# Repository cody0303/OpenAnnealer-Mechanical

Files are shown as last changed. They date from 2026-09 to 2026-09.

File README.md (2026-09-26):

# OpenAnnealer — Mechanical

Mechanical design and assembly for [OpenAnnealer](https://github.com/cody0303/OpenAnnealer), an
automated induction annealer for cartridge cases. This repo covers the physical side only — case
feed, holder, coil mounting, and enclosure. Firmware/electronics live in the main
[OpenAnnealer](https://github.com/cody0303/OpenAnnealer) repo; this split mirrors the upstream
[OpenTrickler](https://github.com/eamars/OpenTrickler) project this fork is based on.

**Status: concept stage.** Design rationale, open assumptions, and next steps are in
[`docs/DESIGN.md`](docs/DESIGN.md) — read that before the CAD, since several parts here are
deliberately placeholders (no induction coil purchased yet, no motor locked in for the spare feed
motor) pending real hardware.

## Layout

- [`docs/`](docs) — design writeup, concept diagrams, photos as the build progresses
- [`cad/`](cad) — source CAD models (OpenSCAD — see [`cad/README.md`](cad/README.md))
- [`stl/`](stl) — print-ready STL exports
- [`assembly/`](assembly) — bill of materials, assembly notes

## Status

Nothing has been bench-tested yet. The design writeup is in [`docs/DESIGN.md`](docs/DESIGN.md).
The whole machine is modelled: the feeder, the funnel and swing arm (up to .338 Lapua Mag), the coil
mount, and the cabinet with its faces and the parts inside it. See [`cad/README.md`](cad/README.md),
which also covers the OpenSCAD nightly requirement, and
[`assembly/assembly.scad`](assembly/assembly.scad) for everything put together. Parts and
fasteners are in [`assembly/BOM.md`](assembly/BOM.md).

[`docs/concept_diagram.svg`](docs/concept_diagram.svg) predates the current feeder design and is
kept only as a sketch of the overall machine.

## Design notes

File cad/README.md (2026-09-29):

# CAD — OpenSCAD source

Parametric, text-based CAD for the printed parts.

## Requirements

**An OpenSCAD nightly build with `import-function` enabled** (Edit → Preferences → Features →
`import-function`). The [catchnhole](https://github.com/mmalecki/catchnhole) submodule uses
OpenSCAD's JSON `import()`, which the 2021.01 release doesn't have.

This matters because it fails *silently*: on a release build every `bolt()` call degrades to
undefined dimensions and renders as a pinhole with no countersink, while still exporting a
clean-looking, printable part. Check the console for `Ignoring unknown function 'import'`.

Clone with the submodule:

```bash
git submodule update --init --recursive
```

Headless render/export:

```bash
openscad --enable=import-function -o singulator.stl cad/feeder/singulator.scad
```

## Layout

- [`sharedDims.scad`](sharedDims.scad) — the dimensions parts share (hardware, stack spacings,
  the cabinet wall); the part files include it rather than hard-coding numbers.
  **Change shared values here, not in a part file.**
- [`feeder/layout.scad`](feeder/layout.scad) — where the feeder stack sits, derived from
  sharedDims; the left panel drills its holes from it.
- [`cabinet/boxLayout.scad`](cabinet/boxLayout.scad) — the cabinet box, what's inside it, and
  every face's cut-outs. Front is the screen end, back is where the USB ports come out, left is the
  panel the feeder mounts on, right is the wall across from it.
- [`feeder/`](feeder) — the feed subsystem, outside the cabinet.
- [`cabinet/`](cabinet) — printed parts inside the cabinet, plus `flatPanel.scad` (the flat-face
  helpers) and `boxLayout.scad`, which aren't parts.
- [`cabinetFlat/`](cabinetFlat) — the cabinet's six faces. The release also exports each one as a
  DXF for cutting (`tools/export_panel_dxf.py`), so nothing but faces belongs here. Faces taller
  than the bed (the ones with a `panelTile` setting) come out of the release as one STL per
  printing tile, `name-upper.stl` and `name-lower.stl`.
- [`../assembly/assembly.scad`](../assembly/assembly.scad) — the whole machine, view only, with
  clash checks. [`../assembly/BOM.md`](../assembly/BOM.md) lists parts and fasteners.

## Parts

| File | Part | Print material |
|---|---|---|
| [`feeder/hopper.scad`](feeder/hopper.scad) | Flat-backed pan; its boss doubles as the wheel's retaining wall, the base plate the case bases ride on, and the motor mount | PLA/PETG |
| [`feeder/singulator.scad`](feeder/singulator.scad) | Wheel with a rim pocket; one per case family, with the size embossed on the face | PETG/nylon |
| [`feeder/shaftAdapter.scad`](feeder/shaftAdapter.scad) | D-bore hub coupling the wheel to the motor shaft | PETG/nylon |
| [`feeder/funnel.scad`](feeder/funnel.scad) | Takes the case from the wheel down into the coil | PETG |
| [`feeder/hornMount.scad`](feeder/hornMount.scad) | Swing arm keyed to the servo's stock horn; carries the M5 thumbscrew the case stands on | PETG/nylon |
| [`cabinet/servoMount.scad`](cabinet/servoMount.scad) | Holds the MG90S inside the left panel | PETG |
| [`cabinet/heatsinkHolder.scad`](cabinet/heatsinkHolder.scad) | Holds the coil's two heatsinks; shares the funnel's upper bolt | PETG |
| [`cabinet/screenTilt.scad`](cabinet/screenTilt.scad) | Tilted screen and knob housing, front wall | PETG |
| [`cabinet/transformerCradle.scad`](cabinet/transformerCradle.scad) | Stand under the transformer (drawn for 15°) | PETG |
| [`cabinet/transformerShim.scad`](cabinet/transformerShim.scad) | Wedge on the cradle that steepens the transformer to 25° | PETG |
| [`cabinet/fanAdapter.scad`](cabinet/fanAdapter.scad) | 40 mm fan duct -- not placed since the driver board stood on end | PETG |
| [`cabinet/cornerBlock.scad`](cabinet/cornerBlock.scad) | Corner block the faces screw into (12 off) | PETG |
| [`cabinetFlat/`](cabinetFlat) | Left panel (`sidePanel`), front, back and right walls, lid and base: 6 mm, printed as tiles or cut from ply | PETG / ply |

## Hardware notes

- **Drive pins** are M3 socket-head bolts threading up through the adapter (head recessed in its
  underside) and protruding to engage the wheel. The bolt cavity is scaled 0.95 so the shank is
  2.85mm — a thread-forming fit in plastic. **M3×20** gives ~11mm of engagement into the wheel;
  M3×16 only gives ~7mm.
- **Set screw** is an M3 through a heat-set insert, aligned with the D-flat.
- **Motor bolts** counterbore into the top of the base plate. The wheel rides on that face, so the
  pocket depth (`3 × countersink`) has to exceed the 3mm head height — currently `countersink=1.33`
  for a 3.99mm pocket.

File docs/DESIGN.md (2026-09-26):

# OpenAnnealer — Mechanical Design

Status: **concept / first pass, not yet bench-verified.** This document responds to the mechanical
design brief handed off from the firmware side of the project (see
[OpenAnnealer](https://github.com/cody0303/OpenAnnealer)). It proposes one coherent, buildable
concept for every open mechanical question in that brief, flags every assumption that still needs
a real part or a real case in hand to confirm, and leaves the things that are genuinely still open
as open. Diagram: [`concept_diagram.svg`](concept_diagram.svg).

## Assumptions and open items (read this first)

These are the load-bearing assumptions behind everything below. If any of them are wrong, the
affected subsystem needs rework before it's worth modeling in CAD:

| # | Assumption | Why it matters | Confirmed? |
|---|---|---|---|
| 1 | Case range to support: pistol through magnum, roughly 0.75"–2.85" (19–72 mm) case length | Drives hopper/disk and holder-insert sizing | No — working range, not measured against real cases yet |
| 2 | Induction coil not yet purchased | Coil bore ID and winding height set the minimum clearance the holder column and cook-zone height must fit inside | No — mount is designed adjustable/oversized until a real coil is on hand |
| 3 | Feeder motor and the second ("spare") motor's frame size (NEMA form factor) | Determines mounting bolt patterns | **Not locked** — see [Second (spare) motor mounting](#second-spare-motor-mounting) below; do not cut a fixed bolt pattern for either motor into a structural part |
| 4 | Fabrication: FDM 3D printing for all custom parts | Drives wall thickness, tolerance, and material choices below | Confirmed by you |
| 5 | New enclosure/base, no chassis carryover from OpenTrickler | Frees up the layout | Confirmed by you |

Everything downstream of #1–#3 is written to be **adjustable or swappable**, specifically so that
getting one of these assumptions wrong later costs a reprinted insert, not a redesign.

## Kinematic concept

One column, top to bottom (see diagram):

1. **Hopper** — a flat-backed pan leaning ~45°, loosely filled with cases in bulk (no
   hand-orienting). They stand base-down on its base plate and slide toward the bottom outlet.
2. **Singulator wheel** — driven by the feeder stepper, its rim sitting in the pan's outlet so its
   cylindrical side is the floor under the pile. A pocket in the rim takes one case off the bottom
   of the pile and carries it round, held in by the hopper's retaining wall, to an angled discharge
   bore that drops it into the holder below.
3. **Coil zone** — the case's neck/shoulder ("cook zone") sits inside the induction coil, supported
   from below by a shelf mounted on the swing arm.
4. **Swing arm** — rotates about a vertical pivot, in the horizontal plane, between two servo-
   commanded positions:
   - **HOLD** — shelf positioned directly under the coil bore, case supported.
   - **DROP** — shelf swung just far enough to clear the coil body; case is no longer supported and
     falls straight down.
5. **Drop point** — no funnel or catch tray in this design; the case falls straight down into
   whatever catch area you provide below (sized separately, per your call).

This matches the firmware's model exactly: the servo only ever commands two fixed ratios
(`HOLDER_RATIO_HOLD` / `HOLDER_RATIO_DROP`, see
[`servo_gate.h`](https://github.com/cody0303/OpenAnnealer/blob/main/src/servo_gate.h)) and never
receives a per-case-length or per-caliber value. All length/diameter compensation has to live in
the mechanism, set by hand before a run — which is exactly what the brief specifies ("a simple
swing arm with an adjustment nut... a manual, physical setting, not something the firmware
commands per case").

## Subsystem designs

### Case holder (swing arm)

- A single arm rotates on a vertical pivot shaft, driven by the case-holder servo, between two
  commanded positions (HOLD/DROP). **No mechanical hard-stop hardware is included** — the RC servo
  is inherently position-controlled (it always drives to whichever duty cycle it's told), so the
  servo itself is the repeatable element, exactly as `servo_gate.c` implements it
  (`close_duty_cycle`/`open_duty_cycle`, two fixed values). A physical stop can be retrofitted later
  if bench testing turns up slop under load, but nothing is designed in preemptively.
- The sweep only needs to be large enough for the shelf/case to clear the coil body, not a fixed
  90°+ arc. For an arm of radius `r` (pivot to case centerline) and a coil of outer radius `R`
  (measured from the HOLD centerline, i.e. from the case's position), the chord the case travels at
  swing angle `θ` is `2r·sin(θ/2)`; solving for the angle that just clears the coil plus a small
  margin `m`: `θ_min = 2·asin((R + m) / (2r))`. E.g. at `r` = 50 mm and `R` = 25 mm coil radius with
  a 5 mm margin, `θ_min ≈ 35°` — nowhere near 90°. Longer arms need even less angle for the same
  coil. **Finalize this once a real coil OD and arm radius are chosen**; the diagram shows a small
  sweep as the working assumption instead of the earlier 90–100° figure.
- At the working end of the arm, a **vertical stud** carries a shelf/cup that slides up or down the
  stud and locks with a **thumb nut** — this is the "adjustment nut" from the brief. Raising or
  lowering the shelf changes how far a case sits down into the guide column, which is what lines
  up the case's neck/shoulder with the coil regardless of overall case length. This setting is
  physical and manual, touched once per case type, never per-cycle.
- The shelf top is a **swappable insert cup**, not a single universal pocket. Rim and extractor-
  groove diameters cluster into a handful of families rather than varying smoothly (this is why
  press shellholders come in a fixed set of groups, not one universal size) — a single hole sized
  for a .338 Lapua rim would let a 9mm case rock or tip, and a hole sized for 9mm won't accept a
  magnum rim at all. Four printed insert cups covering the ranges in the table below is a small,
  cheap part count for a large gain in reliability at both ends of the range. Insert retention:
  press-fit shoulder into a shallow recess on the shelf, sized for a firm hand-press fit in PETG
  (no fasteners needed — it's a tool-less swap between range sessions).

### Hopper + singulator wheel

Modelled on ARC Precision / ADG's annealer. **CAD**: [`cad/feeder/`](../cad/feeder) — hand-written,
with every dimension in [`sharedDims.scad`](../cad/sharedDims.scad).

- **Hopper**: a flat-backed pan leaning back ~45°, open at the top for loading. Cases are dumped in
  loose and stand base-down on the pan's base plate, fully contained (52mm of wall depth against a
  44.7mm case). The lean slides the pile down, and the pan's lower sides — converging at
  `feedAngle` — funnel it into the bottom outlet.
- **The wheel's rim sits in that outlet, and its cylindrical *side* is the floor the bottom of the
  pile rests on.** This is the detail that makes the mechanism work and the easiest thing to get
  wrong: cases do not stand on the wheel's *face*, and the pocket is not a hole through the face.
- **Singulator wheel**: a pocket cut into the rim takes one case off the bottom of the pile per
  revolution; the rest of the pile keeps resting on the smooth tread, so surplus cases reject
  themselves. The pocket is recessed so a seated case sits flush with the rim, which lets the
  retaining wall hug the wheel at 2.5mm. Case size is embossed on the face so wheels are
  identifiable.
- **The funnel is derived, not eyeballed**: `singulatorExposureAngle` sets how much of the rim the
  pile can touch; the chord it subtends *is* the outlet width, and the converging sides fall back
  from it at `feedAngle`. Resizing the wheel moves the hopper to match automatically.
- **One part does four jobs.** The hopper's boss is the wheel's retaining wall (z=8–40, covering 72%
  of the case length — enough that the case's centre of mass sits well inside it), its lower 8mm is
  the base plate the case bases ride on, and the motor bolts straight to the underside — so one
  printed part carries the lot, with no stack-up between separate plates.
- **Discharge** is an angled bore at the bottom of the wheel: the case slides axially out of its
  pocket through the base plate, and the bore's 30° tilt steers it clear of the motor. It opens a
  ~40° release window in the retaining wall.

Verified numbers at the current dimensions (80mm wheel, 100×100 pan):

| Check | Value |
|---|---|
| Chute alignment to the case at bottom-of-rotation | 0.33mm |
| Chute to NEMA17 body | 3.85mm (tightest clearance in the assembly) |
| Outlet chord vs. case diameter | 5.89× (hopper practice wants 4–6× to avoid bridging) |
| Hopper capacity | ~56 cases realistic, 47 pessimistic |

Capacity is the one sitting on its requirement rather than clear of it — the 50-case target is met
on a realistic packing estimate and missed on a pessimistic one. It's derived from packing
geometry, so it's worth checking against a real handful of brass.

This subsystem still needs bench iteration: pickup reliability (hopper lean, pocket depth, tread
width) is not something drawings settle.

### Coil mount

- Since no coil is bought yet, the mount is deliberately **not** built around specific coil
  dimensions. It's a bracket with a **vertical slot** on at least one side, so coil height is
  field-adjustable with a single screw once a real coil arrives — this sets which part of the case
  ends up in the strongest field region without redesigning anything.
- Minimum bore clearance to design toward: the holder column's largest liner OD plus wall
  thickness plus a few mm working clearance — call it **≥25 mm clear ID** through the coil as a
  starting target. **This number must be checked against the actual coil once purchased** before
  finalizing the guide-column OD; it's the one dimension in this document most likely to force a
  revision.

### Drop point

- No funnel or catch tray in this design — the case falls straight down from the DROP position.
  Catch-area sizing/placement is on you; this repo only needs to keep the drop point's location
  (position under the coil, height above your bench/tray) documented once the frame is built, so a
  catch area can be sized against it.

### Second (spare) motor mounting

The firmware brief describes this as hardware-present-but-unused, reserved for a future
feed-path function, "no mechanical role assigned yet." Since you're not locked to a specific motor
for either the feeder or this spare position, **no structural part in this design commits to a
fixed motor bolt pattern.** Concretely:

The feeder motor itself *is* mounted — it bolts straight to the underside of the hopper's base
plate ([`cad/feeder/hopper.scad`](../cad/feeder/hopper.scad)), which is the only part carrying a
motor bolt pattern. Two details there are easy to get wrong: the heads counterbore into the *top*
of that plate, which is the face the wheel runs on, so the pocket has to be deeper than the 3mm
head height (`countersink=1.33` gives 3.99mm); and the bolt circle has to stay clear of the
discharge bore.

For the **second, still-unassigned** motor:

- Reserve a flat, unobstructed mounting **envelope** near the hopper/singulator (roughly
  50×50 mm clear area plus shaft clearance) rather than drilling a bolt circle now.
- When a motor is actually chosen for this position (and, if it turns out to differ from what's
  currently on the feeder, for that one too), the mounting bolt pattern goes on a small
  **printed adapter plate** — a single reprintable part between the motor and the frame — instead
  of being cut into the main structure. NEMA 14 and NEMA 17 motors use different bolt spacing
  (26 mm vs. 31 mm square, respectively); an adapter plate absorbs that difference for the cost of
  one reprint instead of a structural rework.
- No specific future function (hopper advance, multi-case carousel, etc.) is assumed here — the
  brief is explicit that none has been designed yet, and committing this document to one would be
  guessing.

### Frame / base

- New enclosure, no chassis carryover. Hopper + singulator disk → coil → holder → open drop point,
  mounted to a flat base plate; electronics enclosure (LCD/encoder module, control board) mounts
  wherever is convenient on or beside the base — no mechanical constraint from that side beyond
  enclosure volume, per the brief.

## Case-family reference groups (working assumption)

Used to size the swappable disks and holder inserts above. These are standard published SAAMI
case dimensions, not measurements — **verify against your actual cases before cutting the first
insert**, especially at the top end (this document assumes "magnum" tops out around .338 Lapua
Magnum-class, not the largest belted or beltless magnums that exist):

| Family | Example calibers | Case length range | Rim/groove Ø range |
|---|---|---|---|
| Small (pistol/small rifle) | 9mm Luger, .380 ACP, .223/5.56 | ~17–45 mm | ~9.5–9.7 mm |
| Medium | .45 ACP, .30-30, .243 Win | ~23–52 mm | ~11.2–12.0 mm |
| Large | .308 Win, .30-06, .270 Win | ~51–64 mm | ~12.0 mm |
| Magnum | .300 Win Mag, .338 Lapua Mag | ~64–72 mm | ~12.0–14.9 mm (belted magnums: belt Ø ~13.0 mm) |

If real use turns out to need calibers past .338 Lapua Magnum (e.g. .50 BMG-class), that's a fifth
family and a larger coil, not a change to this structure.

## Servo torque sanity check

Brief specifies a TowerPro SG90/MG90S-class servo (per the firmware README). Worst case load is
the heaviest case + insert cup, at the arm's working radius:

- Heaviest case (empty .338 Lapua Mag brass): ~26 g
- Insert cup + shelf hardware: ~15 g estimated
- Arm radius to load: ~50 mm (0.05 m)

Static torque required: `(0.026 + 0.015) kg × 9.81 m/s² × 0.05 m ≈ 0.020 N·m ≈ 0.21 kgf·cm`

MG90S rated stall torque is ~2.2 kgf·cm (4.8 V) / SG90 ~1.6 kgf·cm — roughly **8–10× margin** even
at the heaviest end of the range, before accounting for the servo's own gear-hold. No torque
concern with the specified servo; this isn't a constraint on arm length or insert weight within
any sane design.

## Materials and fabrication (FDM)

- **Near the coil** (holder shelf, insert cups, coil mount bracket, drop chute): use **PETG or nylon**, not PLA/ABS. These parts sit closest to a part that gets hot
  and radiates during dwell; PLA softens around 60°C and ABS around 100°C, both low enough to be a
  real concern this close to an induction-heated case. PETG (~80°C HDT) is the practical minimum;
  nylon is better if you see any softening in testing.
- **Away from the coil** (base plate, hopper, motor mounts): PLA or PETG is fine — no thermal
  exposure to plan around.
- Standard FDM tolerances (±0.2 mm) are fine everywhere except the insert-cup-to-shelf press fit —
  plan a test coupon for that before printing full-size parts, since press-fit tolerance is
  printer- and material-dependent.

## Bill of materials (mechanical, first pass)

See [`assembly/BOM.md`](../assembly/BOM.md).

## Next steps requiring physical hardware (not deferrable to more writing)

1. **In progress**: [`cad/feeder/`](../cad/feeder) has a first-pass hopper + singulator disk + face
   plate + drive hub, sized for a .223 Rem/5.56 NATO prototype off SAAMI reference dimensions —
   verify those against real fired brass with calipers before printing full-size parts (`cad/`
   README has the two fits worth test-coupon-ing first: the drive pin fit and the magnet press-fit).
2. Print that first prototype and bench test hopper pickup reliability and singulation before
   committing to CAD for the other three case families (Small/Medium/Magnum) or for the holder
   assembly below it. Pickup reliability (hopper angle, disk tilt, pocket depth) is the part most
   likely to need several iterations — plan for that rather than expecting the first print to work.
3. Purchase the induction coil; re-check the ≥25 mm clear-bore target and recompute the arm's
   minimum swing angle (formula above) against its actual OD.
4. Decide the second motor before modelling a mount for it — and confirm the feeder motor's actual
   shaft diameter and flat depth against `shaftDia`/`shaftDwidth` in
   [`cad/sharedDims.scad`](../cad/sharedDims.scad).
5. Model the holder swing arm, shelf, insert cup, coil mount bracket, and drop chute — not started
   yet; the feeder subsystem above was the starting point.

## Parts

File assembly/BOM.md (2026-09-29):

# Bill of Materials

Status: work in progress. Everything below is modelled and checked in `assembly/assembly.scad`;
nothing has been bench-tested. Screw lengths assume 6 mm cabinet faces (`cabinetWallThk` in
`cad/sharedDims.scad`) — re-check them if that changes.

## Printed parts (FDM)

| Part | Material | Qty | Notes |
|---|---|---|---|
| Hopper (pan) | PLA/PETG | 1 | Boss doubles as wheel retaining wall, base plate and motor mount — `cad/feeder/hopper.scad` |
| Singulator wheel | PETG/Nylon | 1 per case family | Rim pocket, size embossed on the face — `cad/feeder/singulator.scad` |
| Shaft adapter | PETG/Nylon | 1 | D-bore hub, couples wheel to motor shaft — `cad/feeder/shaftAdapter.scad` |
| Funnel | PETG | 1 | Wheel discharge down into the coil — `cad/feeder/funnel.scad` |
| Horn mount | PETG/Nylon | 1 | Keys to the servo's stock horn; carries the thumbscrew — `cad/feeder/hornMount.scad` |
| Servo mount | PETG | 1 | MG90S hangs in it on its ears — `cad/cabinet/servoMount.scad` |
| Heatsink holder | PETG | 1 | Holds the two coil heatsinks — `cad/cabinet/heatsinkHolder.scad` |
| Screen housing | PETG | 1 | Tilted screen and knob, front wall — `cad/cabinet/screenTilt.scad` |
| Transformer cradle | PETG | 1 | Stand under the transformer, drawn for 15° — `cad/cabinet/transformerCradle.scad` |
| Transformer shim | PETG | 1 | Wedge on the cradle's slab, steepens the transformer to 25° — `cad/cabinet/transformerShim.scad` |
| Fan duct | PETG | 1 | 40 mm fan — not placed yet since the driver board stood up — `cad/cabinet/fanAdapter.scad` |
| Corner block | PETG | 12 | Four vertical corners × base, seam and lid — `cad/cabinet/cornerBlock.scad` |

## Cabinet faces

6 mm, either printed or cut from plywood from the DXF (`tools/export_panel_dxf.py`, or the release
artifacts). The front, back, left and right walls are taller than the 200 mm bed; printed, each is
two tiles joined by a half-lap, glued and bolted. The release has each tile as its own STL
(`frontWall-upper.stl`, `frontWall-lower.stl`, …).

| Face | File | Notes |
|---|---|---|
| Left panel | `cad/cabinetFlat/sidePanel.scad` | The feeder stack, heatsink holder, servo mount and Pico board bolt to it |
| Front wall | `cad/cabinetFlat/frontWall.scad` | Screen housing |
| Back wall | `cad/cabinetFlat/backWall.scad` | Pico board's USB-C ports, IEC inlet |
| Right wall | `cad/cabinetFlat/rightWall.scad` | Corner-block screws only, for now |
| Lid | `cad/cabinetFlat/lid.scad` | Nothing mounted to it, for servicing |
| Base | `cad/cabinetFlat/base.scad` | Transformer cradle screws up into it |

Each wall file has `feederSide`; a right-hand build exports its faces with `"right"`.

## Fasteners

| Item | Spec | Qty | Where |
|---|---|---|---|
| M5 bolt | M5×20 button head | 6 | Through the left panel into captive nuts: hopper 2, servo mount 2, funnel lower 1, heatsink holder bottom 1 |
| M5 bolt | M5×25 button head | 1 | Through the left panel, the heatsink holder and into the funnel's upper nut |
| M5 nut | hex | 7 | Captive in the hopper, servo mount, funnel and heatsink holder |
| Thumbscrew | M5, ~50 long, + 2 jam nuts | 1 | Case stop in the horn mount; shorter cases ride up it |
| M3 screw | M3×10 button head | 32 | Through the faces into the corner blocks |
| M3 heat-set insert | `m3InsertD` × `m3InsertDepth` | 36 | Corner blocks, 3 each (the seam blocks' third one is unused) |
| M3 bolt + nut + washer | M3×10 button head | 7 | Tile half-lap bolts, nut inside (left 1, front 2, back 2, right 2) |
| M3 screw | M3×10 | 4 | Front wall into the screen housing's ear inserts |
| M3 heat-set insert | | 4 | Screen housing ears |
| M3 self-tapper | ~M3×6 | 4 | Screen board onto the housing's standoffs |
| M3 screw + washer | M3×10 | 4 | Up through the base's slots into the cradle's feet; the washers bridge the slots |
| M3 heat-set insert | | 4 | Transformer cradle feet |
| Zip tie | ≤5 mm wide | 2 | Over the transformer, through the shim and cradle |
| M3 screw | M3×10 | 4 | Wall into the fan duct's inlet inserts (fan not placed yet) |
| M3 screw | M3×25 | 4 | Through the fan into the duct's seat inserts |
| M3 heat-set insert | | 8 | Fan duct: 4 in the inlet face, 4 in the seat |
| M3 standoff | M3×10 female–female | 4 | Pico motor board off the left panel |
| M3 screw | M3×10 / M3×6 | 4 / 4 | Standoffs: through the panel / through the board |
| M4 heat-set insert | `m4InsertD` × `m4InsertDepth` | 2 | Heatsink holder, one each side |
| M4 screw | length to suit the heatsinks | 2 | Heatsinks onto the holder |
| Motor screw | M3 socket head | 4 | Counterbored into the top of the hopper's base plate |
| Drive pin | M3×20 socket head | 2 | Thread into the shaft adapter, protrude ~11 mm into the wheel. M3×16 only reaches ~7 mm |
| Hub set screw | M3 grub + heat-set insert | 1 | Bears on the shaft's D-flat |
| Horn screws | the servo's own small self-tappers | 2+ | Horn into the horn mount |

## Other hardware

| Item | Qty | Notes |
|---|---|---|
| Grommet, for an 11 mm hole | 2 | Coil leads through the left panel |
| Edge trim (optional) | ~60 mm | The 18 × 8 stepper cable slot in the left panel |
| 40 × 20 mm fan | 1 | 32 mm hole pitch |
| NEMA 17 stepper | 1 | Feeder wheel |
| MG90S servo | 1 | Swing arm |
| Pico motor expansion board + Pico 2 W | 1 | eamars/RaspberryPi-Pico-Motor-Expansion-Board |
| IEC inlet with switch | 1 | 47 × 27.5 mm panel cut-out, low on the back wall above the relay; up to ~35 mm deep behind the wall |
| Double-sided mounting tape | — | Driver board and relay |

The coil, its heatsinks, the transformer and the driver board are harvested from an induction
heater; confirm their sizes against `cad/cabinet/boxLayout.scad`.

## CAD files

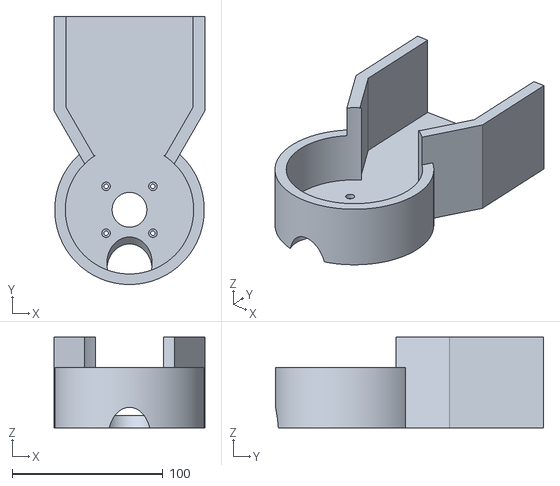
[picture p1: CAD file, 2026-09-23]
stl/hopper.stl
100.0 x 177.5 x 60.0

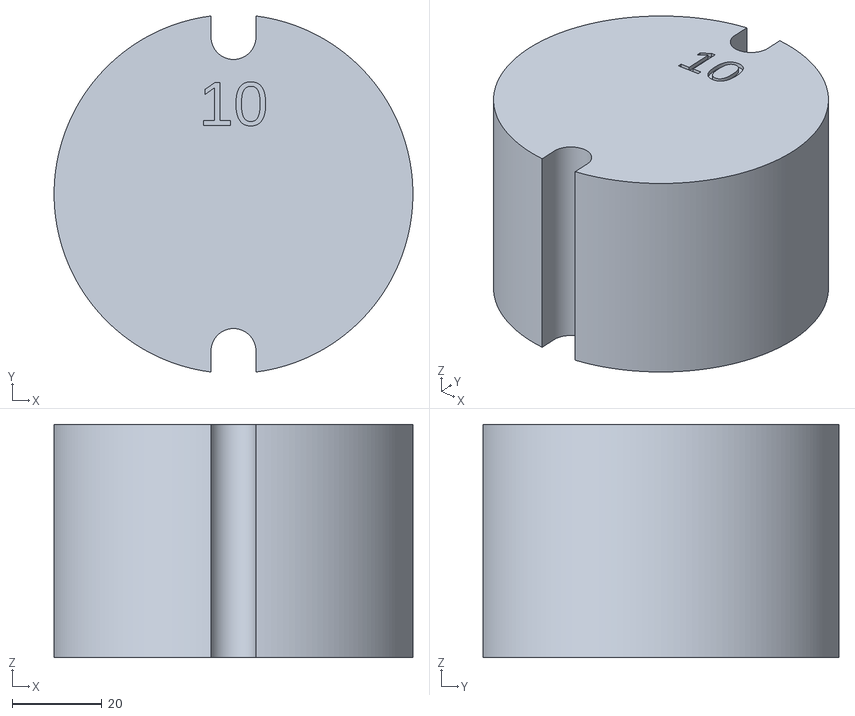
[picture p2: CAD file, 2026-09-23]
stl/singulator1.stl
80.0 x 79.4 x 52.0

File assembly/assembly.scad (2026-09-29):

// OpenAnnealer -- full machine assembly preview.
//
// Open this file and hit F5. It pulls the real part files in from cad/feeder/,
// so it always reflects whatever the parts currently are: edit hopper.scad or
// singulator.scad and this updates with them. Nothing here is a copy of a part.
//
// Lives in assembly/ rather than cad/ on purpose -- the release workflow runs
// `find cad -name "*.scad"` and renders every hit to STL, and this is a
// view-only file, not a part. Don't export it.
//
// Only things with no source file are modelled locally: the motor, servo,
// induction coil, thumbscrew, grommets, the cases, the harvested heater's
// parts and the other electronics. Those are rough stand-ins for
// visualisation, not parts to print.
//
// Where everything sits comes from cad/feeder/layout.scad (the feeder stack)
// and cad/cabinet/boxLayout.scad (the box and what's in it), which the parts
// share, so their holes always land on the parts. The world frame is in
// layout.scad: Z is the drop axis, the funnel arm points +Y to the cabinet's
// left panel. The box's front, back, left and right are named in boxLayout.
// Stack spacings are in sharedDims.
//
// feederSide flips the unit left/right. It does it by turning the feeder
// +/-90 deg about the drop axis, not by mirroring: the hopper is symmetric
// with mounting on both sides, so the same printed parts build either hand.

include <../cad/feeder/layout.scad>

/* [Feeder] */
/* The feeder leans back by mountAngle and the drop bore is cut at mountAngle
   (both from sharedDims), so the discharge always falls dead vertical.
*/
// which side of the stack the feeder sits, seen from outside the cabinet
feederSide = "left";  // [left, right]

/* [Induction coil mock] */
coilTurns = 4;
coilID    = 26;
coilPitch = 5;          // tube OD and the leads' spacing are in sharedDims

/* [Thumbscrew mock] */
thumbHeadD = 14;
thumbHeadH = 7;
nutAcross  = 9.2;
nutH       = 4;

/* [Mock case -- .338 Lapua Mag, the longest it takes] */
// Approximate. The thumbscrew is raised to put the shoulder/neck junction in
// the middle of the coil. .223 Rem: 44.7, 9.5, 6.4, 32, 38
caseLen      = 69.2;
caseBodyD    = 14.9;
caseNeckD    = 9.5;
caseShoulder = 54.9;    // base to the body/shoulder junction
caseNeck     = 60.9;    // base to the shoulder/neck junction

/* [Coil leads mock] */
leadIntoCabinet = 15;   // how far the leads run on past the wall's inner face, into the heatsinks

/* [Cabinet box] */
/* Flat faces (ply or print, cabinetWallThk thick) -- the left panel
   (cad/cabinetFlat/sidePanel.scad), front, back and right walls, lid and base
   (the other files there) -- screwed into printed corner blocks
   (cad/cabinet/cornerBlock.scad) in the four vertical corners at the base,
   the tile seam and the top. Printed faces split at the seam and meet in a
   half-lap, bolted through with nuts inside. Where everything in and on the
   box sits, and the screen tilt, the harvested heater's pose and the Pico
   board's settings, are in cad/cabinet/boxLayout.scad, which the faces share.
*/
boxCutaway    = false;  // drop the lid, front and right walls to see inside

/* [Display] */
showCases   = true;
showMotor   = true;
showCoil    = true;
showFunnel  = true;
showArm     = true;
showCabinet = true;     // the left panel and the lead grommets
showBox     = true;     // the rest of the cabinet
showElectronics = true;
checkTransformer = false;   // true: draw only where the transformer hits something -- nothing drawn means clear
checkCorners     = false;   // true: draw only where the corner blocks hit the servo, its mount or the swinging arm
armSwing         = 45;      // the arm's swing each way from the drop axis, for checkCorners -- the wall slot limits it
hopperAlpha = 0.35;   // 1 = solid; lower to see the wheel and motor through it
funnelAlpha = 1;
cabinetAlpha = 0.35;     // lower to see the leads and servo inside

// +1 puts the feeder on -X (left, seen from outside), -1 on +X
hand       = (feederSide == "right") ? -1 : 1;
feederSpin = 90 * hand;     // turns the hopper's +/-X side square to the wall

coilR = coilID/2 + coilTube/2;              // coil tube centreline radius
// the mock case's base: shoulder/neck junction mid-coil, no lower than the
// thumbscrew goes
caseSeatZ = max(caseBaseZ, coilZ - caseNeck);

// ---------------------------------------------------------------------------
// The real parts, pulled straight from their own files
// ---------------------------------------------------------------------------
// These are wrapped as modules in their own files and pulled in with `use`.
// hopper, shaftAdapter, funnel and servoMount have to be: they `use
// <catchnhole>` themselves, and a nested `use` resolves relative to whichever
// file pulls it in, so `include`-ing them from here can't find it.
use <../cad/feeder/hopper.scad>;        // provides hopper()
use <../cad/feeder/shaftAdapter.scad>;  // provides shaftAdapter()
use <../cad/feeder/funnel.scad>;        // provides funnel()
use <../cad/cabinet/servoMount.scad>;   // provides servoMount()
use <../cad/cabinet/heatsinkHolder.scad>; // provides heatsinkHolder(), heatsinkHolderSize(), heatsinkHolderBackset()
use <../cad/cabinet/transformerCradle.scad>; // provides transformerCradle(), transformerCradleFit()
use <../cad/cabinet/fanAdapter.scad>;    // provides fanAdapter(), on_seat(), fanAdapterMaxX(), fanAdapterMinX(), fanAdapterScrews(), fanAdapterInlet(), fanAdapterSeatT()
use <../cad/cabinetFlat/sidePanel.scad>; // provides sidePanel(), sidePanelTile(), panelFeatures(), panelSplitZ(), lead_hole_2d()

// The other two have no nested `use`, so they can be pulled straight in.
// If you ever add a `use <...>` to one of them it'll break here, and will need
// the same module wrapper as the ones above.
module part_singulator() { include <../cad/feeder/singulator.scad>; }
module part_hornMount()  { include <../cad/feeder/hornMount.scad>; }
use <../cad/cabinet/screenTilt.scad>;    // provides screenTilt(), screenTiltWallFeatures(), in_plate_frame()

use <../cad/cabinet/cornerBlock.scad>;   // provides cornerBlock()
use <../cad/cabinet/flatPanel.scad>;     // provides flat_part(), flat_tile()

// Where the box and everything in and on it sits -- shared with the faces'
// part files. Needs `hand`, above, and the files it lists `use`d, which they are.
include <../cad/cabinet/boxLayout.scad>

// Takes children drawn in hopper.scad's own frame and puts them in the world:
// lean back, slide the bore exit onto the origin, then spin about the drop axis.
module in_feeder_frame() {
    rotate([0, 0, feederSpin])
     translate([0, -exitTiltY, -exitTiltZ])
      rotate([mountAngle, 0, 0])
        children();
}

// ---------------------------------------------------------------------------
// Stand-ins for things with no source file
// ---------------------------------------------------------------------------
module mock_case() {
    cylinder(d = caseBodyD, h = caseShoulder);
    translate([0,0,caseShoulder])
        cylinder(d1 = caseBodyD, d2 = caseNeckD, h = caseNeck - caseShoulder);
    translate([0,0,caseNeck]) cylinder(d = caseNeckD, h = caseLen - caseNeck);
}

// NEMA17. Z=0 is the motor face; body hangs below, shaft above.
module mock_motor(shaftLen = 24) {
    translate([-21.15,-21.15,-40]) cube([42.3, 42.3, 40]);
    cylinder(d = 22, h = 2);
    cylinder(d = shaftDia, h = shaftLen);
}

module mock_coil() {
    for (i = [0 : coilTurns - 1])
        translate([0, 0, i*coilPitch - (coilTurns-1)*coilPitch/2])
            rotate_extrude() translate([coilID/2 + coilTube/2, 0]) circle(d = coilTube);
}

// A copper tube run through a list of points.
module tube_path(pts, d) {
    for (i = [0 : len(pts) - 2])
        hull() {
            translate(pts[i])     sphere(d = d, $fn = 24);
            translate(pts[i + 1]) sphere(d = d, $fn = 24);
        }
}

// The two coil leads: each leaves its end turn tangentially, heading for the
// wall, closes up to leadGap, then runs straight through the grommet.
module mock_leads() {
    for (s = [1, -1]) {
        turnZ = coilZ + s * (coilTurns - 1) * coilPitch / 2;
        tube_path([
            [s * coilR,     0,              turnZ],
            [s * coilR,     coilR + 5,      turnZ],
            [s * leadGap/2, coilR + 20,     leadZ],
            [s * leadGap/2, clDist + cabinetWallThk + heatsinkHolderBackset() + leadIntoCabinet, leadZ]
        ], coilTube);
    }
}

// The heatsink holder in place: its +X end face on the inside of the wall,
// centred between the leads.
module place_holder() {
    translate([0, clDist + cabinetWallThk + heatsinkHolderSize()[0] - heatsinkLen/2, leadZ]) rotate([0, 0, -90]) children();
}
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

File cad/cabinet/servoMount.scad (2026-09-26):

include <../feeder/layout.scad>
use <../../catchnhole/catchnhole.scad>;

// Holds the MG90S end-on, short end toward the cabinet wall, so the arm's
// swing is symmetric about it and the same mount works with the feeder on
// either side. The servo drops into the pocket from above and hangs on its
// ears; M5 bolts come in through the cabinet wall into captive nuts, the same
// way the hopper and funnel mount.
//
// Origin: output shaft axis. z = 0 is the top face, where the ears sit. The
// face that bolts to the wall is at y = -(servoBackset - cabinetWallThk), so
// +Y points away from the wall, into the cabinet.

//servoClear, servoMountH and servoMountBoltX come from layout.scad, which
//the side panel shares, so its bolt holes always line up with this part
earPilotD   = 1.6;                                      //self-tappers through the servo's ears
mountH      = servoMountH;                              //ear underside down to the case bottom
mountWallY  = -(servoBackset - cabinetWallThk);         //the face against the wall
bodyCenterY = servoBodyL/2 - servoShaftToEnd;           //case centre, from the shaft
mountFarY   = bodyCenterY + servoEarSpan/2 + 3;         //just past the far ear's tip
mountBoltX  = servoMountBoltX;
mountHalfW  = mountBoltX + wallThickness + 4;
//the servo's cable leaves the case at its wall-side end, low down: a notch through
//the mount's end there, open at the bottom, lets it bend straight down against the wall.
//It's set by what's left above it: tilted in for insertion, the servo's cable dips
//to 8 mm below the ears' underside, so no more than that (the wall-side ear's pilot
//breaks into the notch -- fine)
cableNotchW    = 6;
cableNotchRoof = 7;                                     //mount left above the notch -- 8 at most
cableNotchH    = mountH - cableNotchRoof;               //up from the case bottom

assert(bodyCenterY - servoEarSpan/2 > mountWallY,
       "the servo's wall-side ear hits the cabinet wall -- increase servoBackset");
assert(cableNotchRoof <= 8, "the cable notch is too shallow for the servo's cable as it's tilted in");

// Wrapped as a module so assembly/assembly.scad can place it.
module servoMount() {
    difference(){
        //main block
        translate([-mountHalfW, mountWallY, -mountH])
            cube([2*mountHalfW, mountFarY-mountWallY, mountH]);

        //pocket the case drops through
        translate([-(servoBodyW/2+servoClear), -(servoShaftToEnd+servoClear), -mountH-1])
            cube([servoBodyW+2*servoClear, servoBodyL+2*servoClear, mountH+2]);

        //notch for the servo's cable, at the wall-side end
        translate([-cableNotchW/2, mountWallY - 1, -mountH - 1])
            cube([cableNotchW, -(servoShaftToEnd + servoClear) - mountWallY + 2, cableNotchH + 1]);

        //pilots for the ear screws
        for (y = [bodyCenterY-servoEarHolePitch/2, bodyCenterY+servoEarHolePitch/2])
            translate([0, y, -8])
                cylinder(h=9, d=earPilotD);

        //mounting nut interface, mirrored so the mount is symmetric
        for (side = [0, 1]) mirror([side, 0, 0]) {
            translate([mountBoltX, mountWallY+wallThickness, -mountH/2])
                rotate([-90,0,0])
                    nutcatch_sidecut("M5", "hexagon", height_clearance=0.2, width_clearance=0.2);
            translate([mountBoltX, mountWallY, -mountH/2])
                rotate([-90,0,0])
                    bolt("M5", length=(wallThickness+nut_height("M5")+5), kind="headless", length_clearance=1);
        }
    }
}

servoMount();

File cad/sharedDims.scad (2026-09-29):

$fn=180;

/* [Printer] */
printBed            = 200;

/* [Hardware] */
m3InsertD           = 4.0;  //M3 heat-set insert hole -- check your insert's datasheet
m3InsertDepth       = 6.2;  //for a 5.7 mm long insert, plus a little for melt-back
m4InsertD           = 5.0;
m4InsertDepth       = 8.0;

/* [Shaft Adapter] */
adapterDia      = 20;
pinLatOffset    = 6;
numPins         = 2;

//overall
clDist              = 60;

/* [Hopper] */
wallThickness   = 5;
baseThickness   = 8;
hopperWidth     = 100;
hopperHeight    = 50;
hopperDepth     = 60;
hopperConvergeAngle       = 30;
dropHoleSize    = 30;
mountAngle      = 45;
//NEMA17 motor dimensions
shaftSquareDim      = 3;
shaftDia            = 5;
shaftDwidth         = 4.5;
flatLength          = 12;
motorHolePatternX   = 31;
motorHolePatternY   = 31;
motorClearanceCircle= 23;

/* [Singulator] */
singulatorDiameter      = 80;
singulatorExposureAngle = 90;
numHoles                = 4;
caseCutout              = 10;

/* [Funnel] */
topDia              = 40;
exitDia             = 20;
funnelHeight        = 30;

/* [Movable Support] */
supportScrewSize    = 6.6;
supportThickness    = 6;
cabinetWallThk      = 6;  //cabinet faces (ply or print); the servo mount bolts to the inside of the left panel
cornerBlock         = 20; //printed blocks in the cabinet's vertical corners -- at the base, the tile seam and
                          //the top; every wall screws into them
tileLap             = 16; //where a printed wall's two tiles meet: a half-lap this tall, glued and screwed

//MG90S servo -- typical numbers, measure yours
servoBodyL          = 22.8; //case length, along the ears
servoBodyW          = 12.2;
servoBodyH          = 22.7; //case bottom to case top, not counting the output boss
servoShaftToEnd     = 6.1;  //output shaft centre to the short end of the case
servoEarSpan        = 32.2; //tip to tip of the mounting ears
servoEarHolePitch   = 27.8;
servoEarThk         = 2.5;
servoEarDrop        = 4.0;  //case top down to the top face of the ears
servoWallClear      = 1.2;  //air between the servo's wall-side ear and the inside of the cabinet wall
servoEarsToArm      = 13.5; //measured: the servo mount's top face (the ears' underside) up to the arm's underside, horn on
//distance from the outside wall of the box to the servo's axis: the wall, then as far as the
//wall-side ear reaches from the shaft (half the ear span, less the case centre's offset
//behind the shaft), then the clearance. It has to come after the servo numbers it uses.
servoBackset        = cabinetWallThk + (servoEarSpan/2 - (servoBodyL/2 - servoShaftToEnd)) + servoWallClear;

//stack spacing down the drop axis
dropToFunnelRim     = 18;   //discharge exit down to the funnel's top rim
funnelToCoil        = 15;   //funnel exit down to the centre of the coil
maxCaseLen          = 69.2; //the longest case it takes (.338 Lapua Mag); shorter ones ride up the thumbscrew
funnelToCase        = maxCaseLen + 7;   //funnel exit down to the thumbscrew head at its lowest: the longest
                                        //case, with its mouth clear of the funnel
caseToArm           = 16;   //thumbscrew head at its lowest down to the top face of the horn arm

/* [Heatsink Holder] */
//induction heater heatsinks -- the pair on the heatsink holder, inside the cabinet; the coil's
//leads come through the wall and plug into them, and the transformer's cables leave the far end
heatsinkSpacing     = 20;   //between their flat faces: the holder's width across them
heatsinkH           = 54;   //overall, across the fins
heatsinkFinReach    = 5.25; //the fins stand this far proud of the flat face, toward the holder
heatsinkDepth       = 18.5; //flat face out to the back of the curved base (round, not square -- see layout)
heatsinkLen         = 38;   //extrusion length, the same as the holder
heatsinkBoreIn      = 7;    //the coil's lead plugs in this far in from the flat face, at mid-height

//the driver board's fan -- a standard 40 x 20
driverFanSize       = 40;   //square
driverFanDepth      = 20;
driverFanHolePitch  = 32;   //between its screw holes (M3)

//induction coil leads, where they pass through the cabinet wall
coilTube            = 4;    //copper tube OD
leadGap             = heatsinkSpacing + 2*heatsinkBoreIn;   //centre-to-centre: the heatsinks' lead bores
grommetLip          = 2.5;  //the pass-through is grown by this for the grommet
wallBackset         = 0; 

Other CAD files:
cad/cabinet/boxLayout.scad
cad/cabinet/cornerBlock.scad
cad/cabinet/fanAdapter.scad
cad/cabinet/flatPanel.scad
cad/cabinet/heatsinkHolder.scad
cad/cabinet/screenTilt.scad
cad/cabinet/transformerCradle.scad
cad/cabinet/transformerShim.scad
cad/cabinetFlat/backWall.scad
cad/cabinetFlat/base.scad
cad/cabinetFlat/frontWall.scad
cad/cabinetFlat/lid.scad
cad/cabinetFlat/rightWall.scad
cad/cabinetFlat/sidePanel.scad
cad/feeder/funnel.scad
cad/feeder/hopper.scad
cad/feeder/hornMount.scad
cad/feeder/layout.scad
cad/feeder/shaftAdapter.scad
cad/feeder/sharedDims.scad
cad/feeder/singulator.scad

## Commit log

2026-09-11 Add first-pass mechanical design concept and repo scaffolding
    Covers case holder, feed/singulation, magazine, coil mount, tray, and
    motor mounting provision in response to the firmware brief. Flags open
    assumptions (case range, no coil purchased yet, motor frame size not
    locked) that need real hardware to resolve before CAD.
2026-09-11 Rework feed mechanism to hopper + tilted singulator disk
    Replaces the earlier vertical-magazine/escapement-wheel and 45-degree
    queued-tube concepts, both wrong per bench feedback. Modeled on the ARC
    Precision annealer's real feeder: a wide V-trough hopper drops loose,
    un-oriented cases onto a single-pocket disk tilted ~45 degrees, which
    rides a stationary face plate and releases one case at a discharge
    cutout. Also shrinks the holder arm's swing to a geometry-driven
    minimum (was an arbitrary 90-100 degrees), removes the unneeded
    mechanical hard-stop framing (the RC servo's own commanded position is
    the repeatable element), and drops the catch-tray/funnel subsystem
    entirely per direction to s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
2026-09-11 Add OpenSCAD CAD for the feeder: hopper, singulator disk, face plate, hub
    First real CAD, sized for a .223 Rem/5.56 NATO prototype off SAAMI
    reference dimensions (needs caliper verification before printing).
    - cad/lib/dimensions.scad: single source of truth for every measurement,
    with assertions that catch a future edit breaking the hub/disk/face-
    plate fit
    - cad/feeder/drive_hub.scad: mounts once on the feeder motor's 5mm
    D-shaft; the only fastener ever touched is its one grub screw
    - cad/feeder/singulator_disk.scad: swappable per case-family, pops onto
    the hub via 3 drive pins (torque) + 3 embedded magnets (retention) --
    no grub screw fighting to swap calibers, per bench feedbac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
    [drive_hub.scad, face_plate.scad, feeder_assembly.scad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]
2026-09-11 Fix hub magnet pockets breaking through outer wall, add renders
    Installed OpenSCAD and rendered every feeder part headlessly to
    actually verify the geometry instead of just reviewing the code by
    eye. Caught a real bug this way: HUB_OD=30 wasn't big enough to
    contain the magnet pockets at MAGNET_ORBIT_R=14, so they broke through
    the hub's outer wall. Bumped HUB_OD to 40 and added assertions so this
    can't silently regress. Everything else (hopper taper, disk/face-plate
    hole placement, hub/disk/face-plate stack spacing) checked out visually
    against the renders in cad/renders/.
2026-09-11 Rebuild hopper as an open scoop with the disk face as its floor
    The previous hopper was a closed square funnel sitting on top of the
    disk, which missed the mechanism entirely. Re-read against the ARC/ADG
    reference photos: there is no separate hopper floor -- cases stand
    packed on their bases directly against the singulator disk's face,
    axes perpendicular to it, and the ~45 degree lean both presses those
    bases flat against the disk (so one can drop axially into the pocket)
    and shuffles the pile down-slope toward the pickup zone.
    - hopper.scad: retaining collar at disk diameter + flared mouth, with
    an angled scoop cut bounded to the up-slope sector. Bounding it to a
    sector is what leaves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
    [feeder_assembly.scad, hopper.scad]
2026-09-11 Rebuild feeder around a rim-scalloped wheel and flat-backed hopper pan
    Fourth correction to this mechanism, and the one that finally reconciles
    the ARC/ADG reference photos. The capture feature is a half-round
    SCALLOP CUT INTO THE WHEEL'S RIM, not a hole through its face, and the
    wheel's cylindrical SIDE is the hopper's floor at the outlet. Cases lie
    parallel to the wheel's axis, so a case and a scallop are two parallel
    cylinders that nest exactly.
    - hopper.scad: rebuilt on Cody's pan geometry -- flat back plate,
    perimeter walls, sides converging at feedAngle, open top and bottom.
    Folds in the circular bottom outlet from his hopper_correct.scad
    sketch, fixing two bugs in it along the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
    [back_plate.scad, drive_hub.scad, face_plate.scad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]
2026-09-11 Scale feeder for a 50-case hopper; derive funnel from singulator
    Cody's dimensions were placeholders and the hopper needs to hold 50+
    cases, so the whole subsystem is resized around that requirement.
    - Adopts the funnel derivation from his hopper_correct.scad: an
    exposure angle subtends a chord across the wheel, that chord is the
    outlet width, and the converging sides fall back from it at
    feedAngle. The funnel now always lands where the rim emerges, and
    moves automatically if the wheel is resized. Both bugs from the
    earlier draft are gone in his version (height= not depth=, translate
    outside the extrude).
    - Hopper 40x50 -> 85x90, giving ~54 cases. dimensions.scad computes the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
    [feeder_assembly.scad, hopper.scad]
2026-09-11 Ignore local scratch CAD files
    Keeps hopper_correct.scad on disk as scratch without it showing up as
    untracked noise in git status on every commit.
2026-09-11 Add feeder motor bracket -- the motor had no mount at all
    Until now drive_hub.scad clamped the motor's shaft and back_plate.scad
    had three M3 holes labelled "into the housing", but no housing existed
    and nothing positioned the motor coaxially with the wheel or gave its
    reaction torque a load path.
    - motor_bracket.scad: motor bolts to its rear face; three standoffs tie
    it to the back plate's existing mount circle so motor, plate and wheel
    share one axis. It is deliberately the ONLY part carrying a motor bolt
    pattern, so an unlocked frame size costs one reprinted plate.
    - Two clearances that looked fine by eye are now asserted. The first
    caught a real bug immediately: the bolt-clockin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
    [feeder_assembly.scad, motor_bracket.scad]
2026-09-11 Fix case/hopper interference and shroud overlap at the outlet
    Cody asked whether cases would jam in the curved part of the hopper.
    Checking the numbers found two real defects there, neither of them
    friction:
    1. A case seated in a scallop reaches r=29.8 (its centre sits ON the
    rim, so it protrudes half a case past the wheel's surface), but the
    hopper's outlet was cut to the wheel at r=27. That is a 2.8mm hard
    interference exactly where a loaded scallop leaves the pile -- the
    case fouls the hopper wall on its way out.
    2. The shroud spanned 100-250 degrees while the hopper's exposure
    window runs 45-135, so the two parts occupied the same space over a
    35 degree overlap.
    Both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
    [hopper.scad, shroud.scad]
2026-09-23 Deleted all of Claude's attempts. Everything is now hand written.
    [back_plate.scad, drive_hub.scad, hopper.scad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]
2026-09-23 shrank the dims to fit on a regular printer.
    [hopper.scad, hopper.stl, shaftAdapter.scad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]
2026-09-23 Remove superseded CAD and retarget docs at the hand-written feeder
    Follow-up to 4e17ae3, which deleted the generated part files but left
    their scaffolding and every doc reference behind.
    Removed: feeder_assembly.scad (referenced the deleted parts, no longer
    parsed), cad/lib/ (dimensions/shapes/case_model/motor_model - all only
    used by that assembly), and cad/renders/ (snapshots of parts that no
    longer exist).
    Retargeted cad/README.md, assembly/BOM.md, docs/DESIGN.md and the root
    README at the three real parts. The feeder section of DESIGN.md
    described the old scalloped-rim/shroud/back-plate scheme throughout and
    is rewritten to match what is actually modelled, including the verified
    number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
    [feeder_assembly.scad]
2026-09-23 restrict the search to the cad directory
2026-09-23 Shrink hopper for faster printing, few new parts.
    [funnel.scad, hornMount.scad, sharedDims.scad]
2026-09-24 First real prototypes
    Shrink hopper for faster printing, few new parts. Restructured the funnel and horn mount to share dims. Added chamfer on the singulator entrance slot.
    [funnel.scad, hornMount.scad, shaftAdapter.scad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]
2026-09-24 fix text on singulator
    [singulator1.scad]
2026-09-24 singulator branding
    [singulator1.scad]
2026-09-24 Add assembly preview that references the part sources directly
    assembly/assembly.scad composes the real part files rather than a
    snapshot, so it tracks whatever the parts currently are. Lives in
    assembly/ rather than cad/ deliberately: the release workflow runs
    `find cad -name "*.scad"` and renders every hit to STL, and this is a
    view-only file.
    Spacings are exposed as variables at the top -- feeder tilt and spin,
    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
    [assembly.scad, hopper.scad, shaftAdapter.scad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]
2026-09-24 Centre the hopper on the motor axis and the assembly on the drop axis
    hopper.scad now puts its origin on the motor/singulator axis, with
    mountAngle and dropHoleSize hoisted into sharedDims. The assembly's world
    Z axis is the drop axis: funnel, coil, case and thumbscrew sit at x=y=0,
    and since the bore and the tilt are both mountAngle the drop is always
    vertical, so the trajectory maths is gone.
    [assembly.scad, hopper.scad, sharedDims.scad]
2026-09-24 Add a cabinet side panel mock with the coil leads running through it
    Flat panel at y = clDist (the funnel arm's end), with an arm slot, the
    funnel screw holes and a grommeted pass-through for the coil leads.
    Leads leave the end turns tangentially and close up to leadGap before
    the wall. Also a rough MG90S under the horn arm, inside the cabinet.
    [assembly.scad]
2026-09-24 Stop the cabinet panel just above the funnel rim
    [assembly.scad]
2026-09-24 Mock a feeder-to-wall bracket and raise the panel back up
    A standoff block between the hopper's +X side and the wall, cut back by
    the hopper's outline and retaining-wall boss so it seats on them, with
    three bolts out through the panel. The feeder transform is now a
    in_feeder_frame() helper so the panel can cut the bolt holes from the
    same positions.
    [assembly.scad]
2026-09-24 Simplify the feeder bracket mock to a plain spacer block
    The hopper will get a flat spot across its side and singulator area, so
    the bracket is now just a block from x = hopperWidth/2 out to the wall.
    Drops the conforming cut, the bolts and their wall holes, and the
    duplicated hopper outline they needed.
    [assembly.scad]
2026-09-25 starting the cabinet integration
    [assembly.scad, funnel.scad, hopper.scad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]
2026-09-25 screen mount, and standardizing hardware dims
    [screenTilt.scad, shaftAdapter.scad, sharedDims.scad]
2026-09-25 further work on the cabinet and screen
    [assembly.scad, hornMount.scad, screenTilt.scad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]
2026-09-26 Cabinet integration
    Continuing through cabinet integration, including adding the heatsinks to the mix
    [assembly.scad, funnel.scad, heatsinkHolder.scad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]
2026-09-26 Continuing cabinet integration work.
    [assembly.scad, backWall.scad, base.scad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]
2026-09-26 adjust servo mount
    [servoMount.scad, sharedDims.scad]
2026-09-26 Fix heatsink holder when extended
    [heatsinkHolder.scad, hopper.scad, sharedDims.scad]
2026-09-26 unround corners
    [sidePanel.scad]
2026-09-26 IEC inlet
    [assembly.scad, backWall.scad, boxLayout.scad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]
2026-09-29 re-arrange transformer because previous position was too far away. Servo bracket fix due to finding in fit.
    [assembly.scad, boxLayout.scad, layout.scad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]
